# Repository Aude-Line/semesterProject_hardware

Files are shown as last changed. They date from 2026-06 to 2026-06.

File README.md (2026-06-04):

# CAD Gripper — Hardware Repository

## Intro

This repository contains all hardware files for the EHD actuated soft gripper project: CAD source files for laser-cut and 3D-printed parts, along with the electronics design for the control and power system.

---

## Repository Structure

```
cad_files/
├── laser_model_2D/        # 2D drawings (PDF) for laser-cut parts
├── source_laser/          # STEP files for laser-cut parts (2 mm acrylic)
└── source_3d_print/       # STEP files for 3D-printed parts (PLA)
```

---

## Electronics

The electronics are an improved version of the system used in the lab. The key change is that instead of the DC-DC converter being always enabled, its enable pin is now controlled by an ESP32-C6, chosen for its MicroROS compatibility. All components are soldered and mounted on the `elec_holder_main_plate` (laser-cut as part of the electronics box). The ESP is power via USB.

### Block Diagram

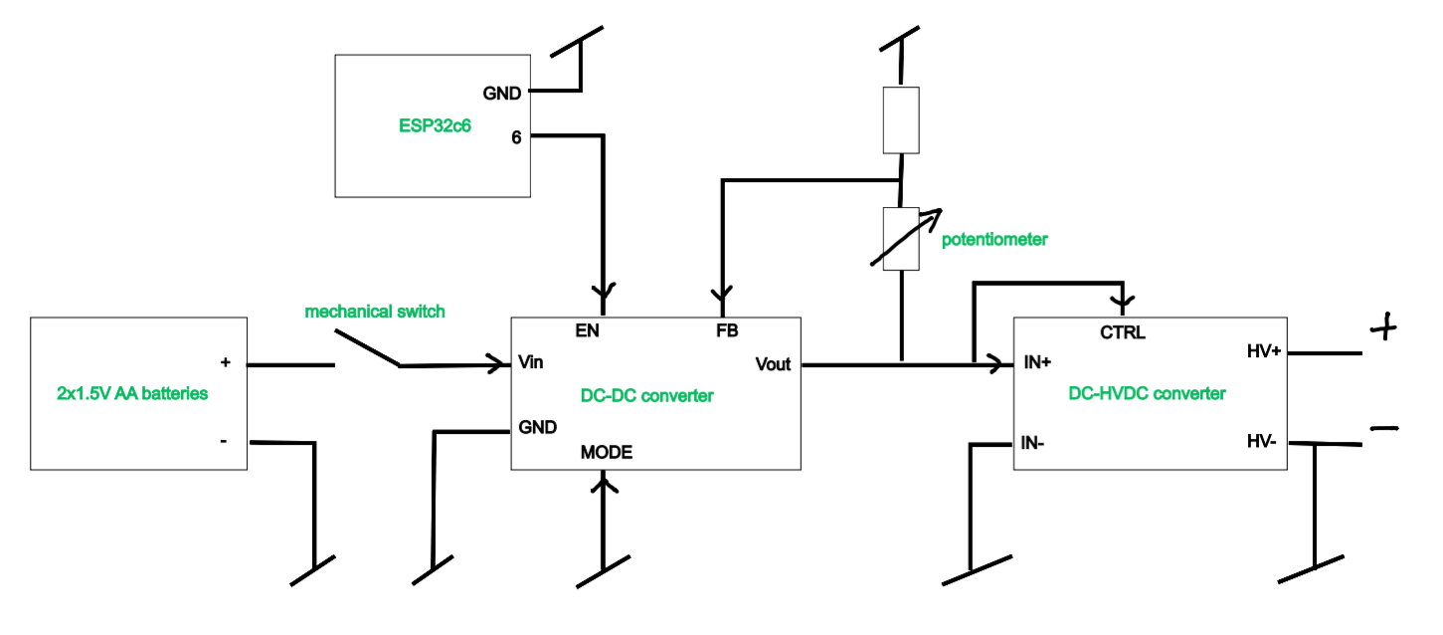
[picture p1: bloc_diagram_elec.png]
Block Diagram


### Components

| Qty | Component | Description |
|-----|---|---|
| 1 | ESP32-C6 dev board | Microcontroller — controls the DC-DC enable pin (https://docs.espressif.com/projects/esp-dev-kits/en/latest/esp32c6/esp32-c6-devkitm-1/user_guide.html)|
| 1 | DC-DC converter | Regulates the battery voltage to supply the HVDC-DC converter (https://www.ti.com/lit/ug/slvuco7/slvuco7.pdf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, https://www.ti.com/lit/ds/symlink/tpsm83100.pdf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)|
| 1 | HVDC-DC converter | High-voltage DC-DC — powers the EHD pump; output is linear to input (https://www.xppower.com/storage/portals/0/pdfs/SF_A_Series.pdf)|
| 1 | Potentiometer | Analog input for output voltage control |
| 1 | Mechanical switch | Safety switch — cuts the circuit |
| 2 | Proto board | Mounting support for the ESP32 and HVDC-DC converter |
| 2 | AA batteries | Main power source |
| 1 | Battery holder | |

---

## Assembly

### Parts List

**Laser-cut (2 mm acrylic):**
- `elec_holder_back_part1` / `elec_holder_back_part2` — Electronics enclosure back panels
- `elec_holder_front` — Electronics enclosure front panel
- `elec_holder_main_plate` — Main mounting plate
- `elec_holder_gripper_attachment` — Gripper-side attachment (top)
- `elec_holder_robot_attachment` — Robot arm-side attachment (bottom)
- `elec_holder_spacer_robot` — Spacer for robot attachment
- `gripper_attachment_silicone` — Silicone gripper attachment interface
- `gripper_direct_attachement_laser` — Direct gripper attachment (laser variant)

**3D-printed (PLA):**
- `elec_holder_bananaPlugs_holder` — Banana plug holder
- `elec_holder_wall_left` / `wall_right` — Side walls for electronics enclosure
- `elec_holder_devBoard_DCDC_holder` — DC-DC dev board mount
- `gripper_direct_attachement_3d` — Direct gripper attachment (3D variant)

---

### Electronics Box Assembly

> The box was originally designed to also house a pump and a liquid pouch. This was later abandoned to improve safety (separating electronics from liquid) and reduce the weight on the robot. Some holes on the top and bottom panels remain from that initial design. As a result, `elec_box part1` only needs to be laser-cut when the box is not used as a gripper support in direct contact with the robot and `elec_box part2` file contains the attachemnt for the robot ant the gripper.

**Components:**
- 1× `elec_holder_wall_right` (3D-printed)
- 1× `elec_holder_wall_left` (3D-printed)
- 1× `elec_holder_devBoard_DCDC_holder` (3D-printed)
- 1× `elec_holder_bananaPlugs_holder` (3D-printed)
- 1× `elec_holder_back_part1` (laser-cut)
- All electronic components
- 12× heat inserts (https://www.bossard.com/ch-en/eshop/threaded-inserts-for-press-in-for-plastic-materials/tappex-multisert-003-004/p/37896/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)

**Assembly steps:**
1. Install the heat inserts
2. Attach the electronics to their respective layers
3. Attach the bottom and both back panels to the walls
4. Slide the layers in, routing the switch and potentiometer to the back panel
5. Close the box with the front panel and screws

> Refer to the assembly video below — note that not all components are rendered.

https://github.com/user-attachments/assets/7390a7a7-a0ae-449d-9c6a-b7f72b6546bb

---

### Gripper Assembly

**Components:**
- 1× `gripper_direct_attachement_3d` (3D-printed)
- 2× silicone modules
- 1× `gripper_attachment_silicone` (laser-cut, 2 mm acrylic)
- 2× heat inserts (https://www.bossard.com/ch-en/eshop/threaded-inserts-for-press-in-for-plastic-materials/tappex-multisert-003-004/p/37896/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)
- Tubing

**Assembly steps:**
1. Connect tubes to the silicone gripper modules
2. Glue the modules onto the small attachment pieces
3. Screw the small attachments into the attachment plate — the modular design allows spacing adjustment and module swapping
4. Install heat inserts in the 3D-printed part
5. Screw the 3D-printed part onto the robot
6. Slide the attachment plate into the 3D-printed part and screw in place if needed

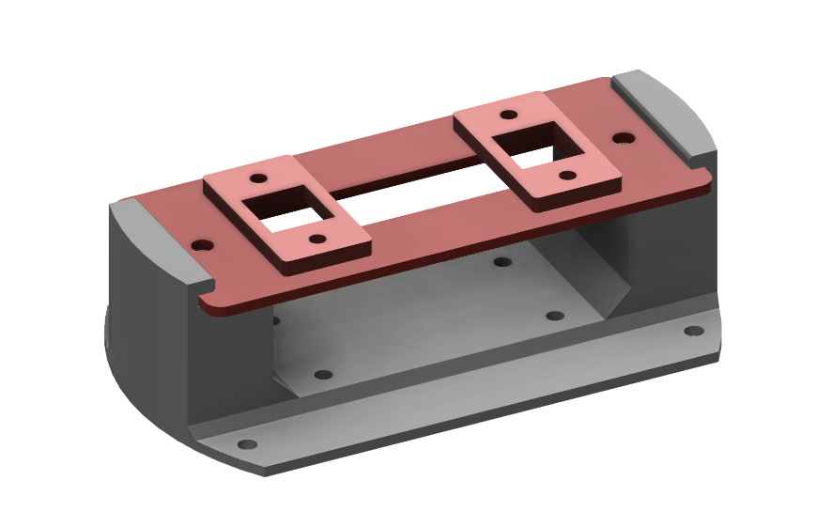
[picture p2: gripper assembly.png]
Gripper Assembly


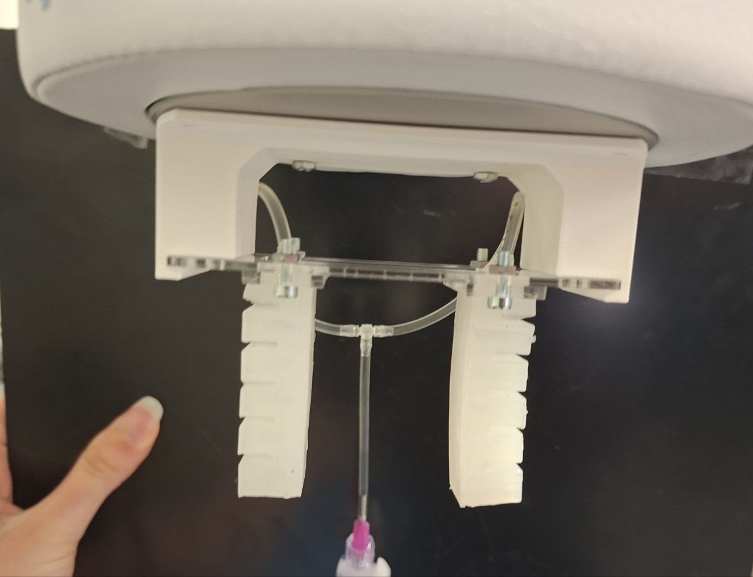
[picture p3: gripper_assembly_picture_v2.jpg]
Gripper Assembly Photo


### Full Assembly

Once every part is tested and validated, the pump can be connected:

1. Mount a liquid reservoir at an elevated position
2. Attach the pump between the reservoir and the gripper tube
3. Fill the system with liquid
4. Connect the pump to the banana plug connectors

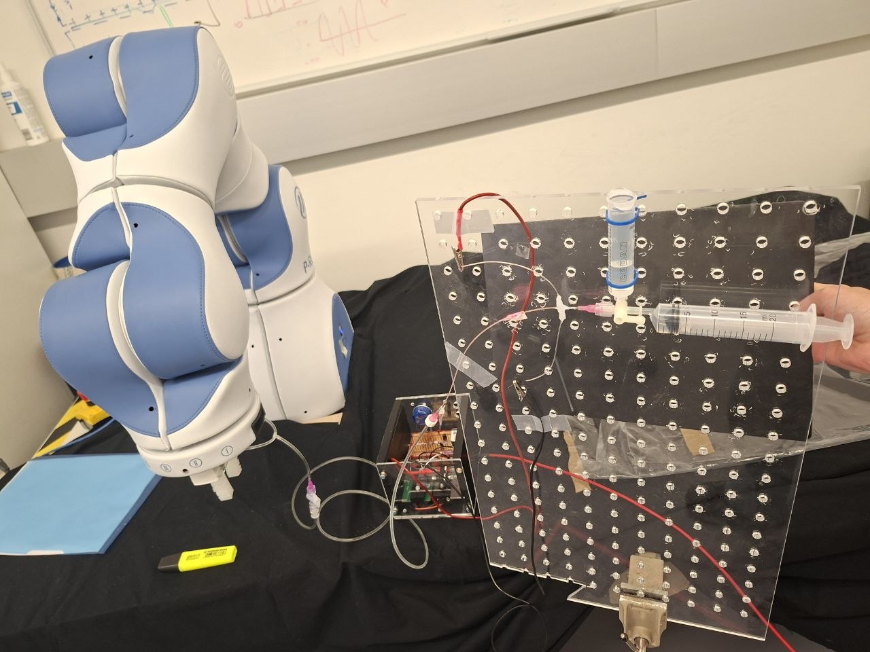
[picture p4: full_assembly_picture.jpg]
Full Assembly


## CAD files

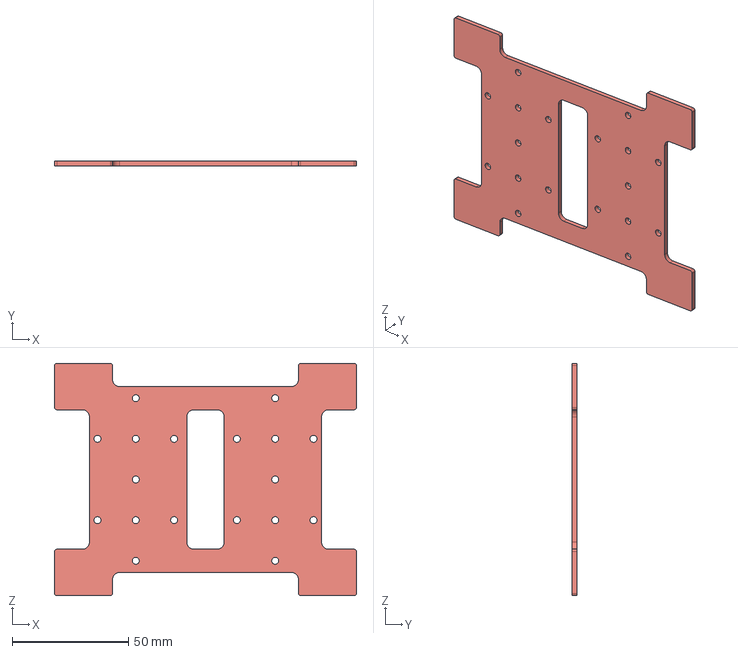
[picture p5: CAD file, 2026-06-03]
cad_files/source_laser/elec_holder_main_plate.step
130.0 x 2.00 x 100.0 mm

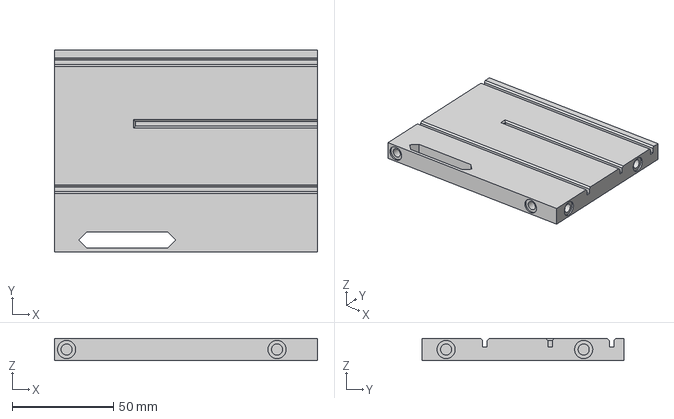
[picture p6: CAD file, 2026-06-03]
cad_files/source_3d_print/elec_holder_wall_left.step
130.0 x 100.0 x 11.0 mm

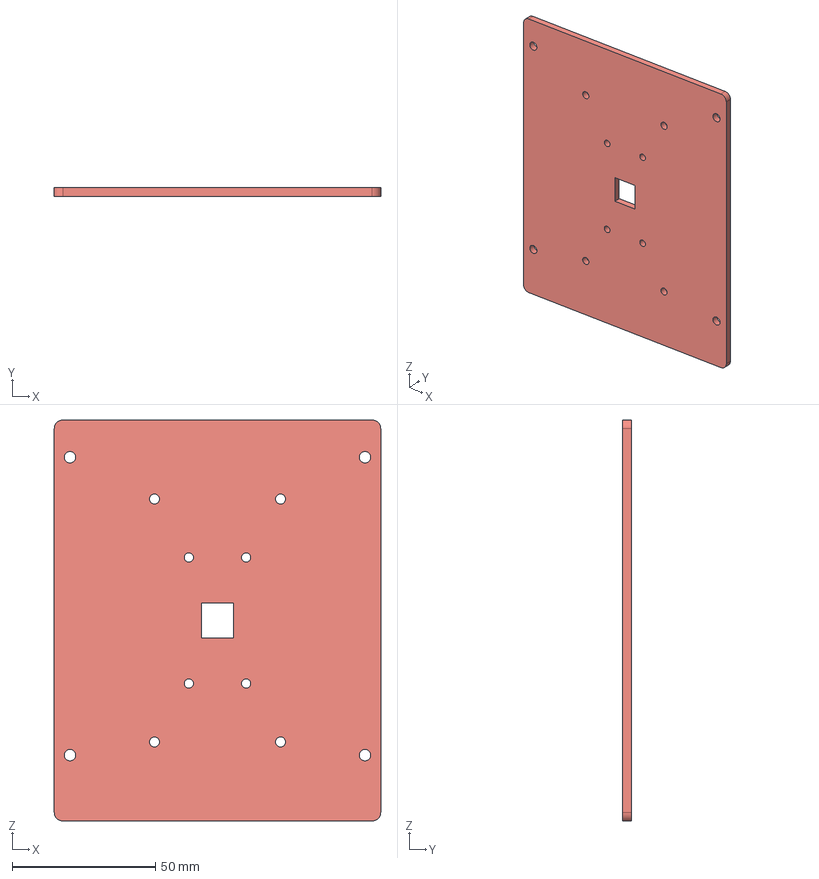
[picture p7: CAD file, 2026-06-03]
cad_files/source_laser/elec_holder_robot_attachment.step
114.0 x 3.00 x 140.0 mm

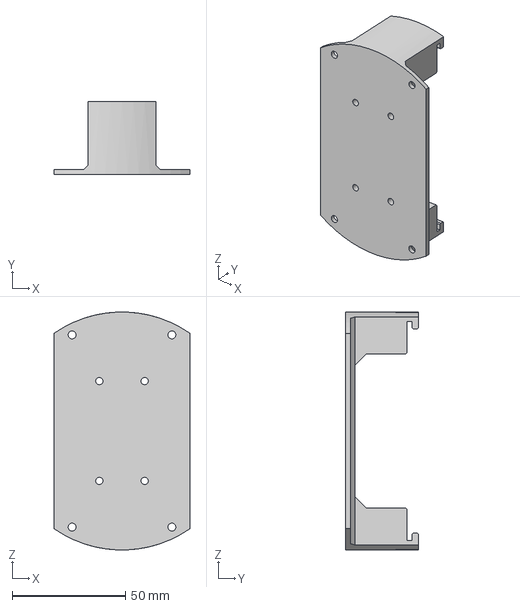
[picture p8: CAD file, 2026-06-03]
cad_files/source_3d_print/gripper_direct_attachement_3d.step
60.0 x 32.0 x 105.0 mm

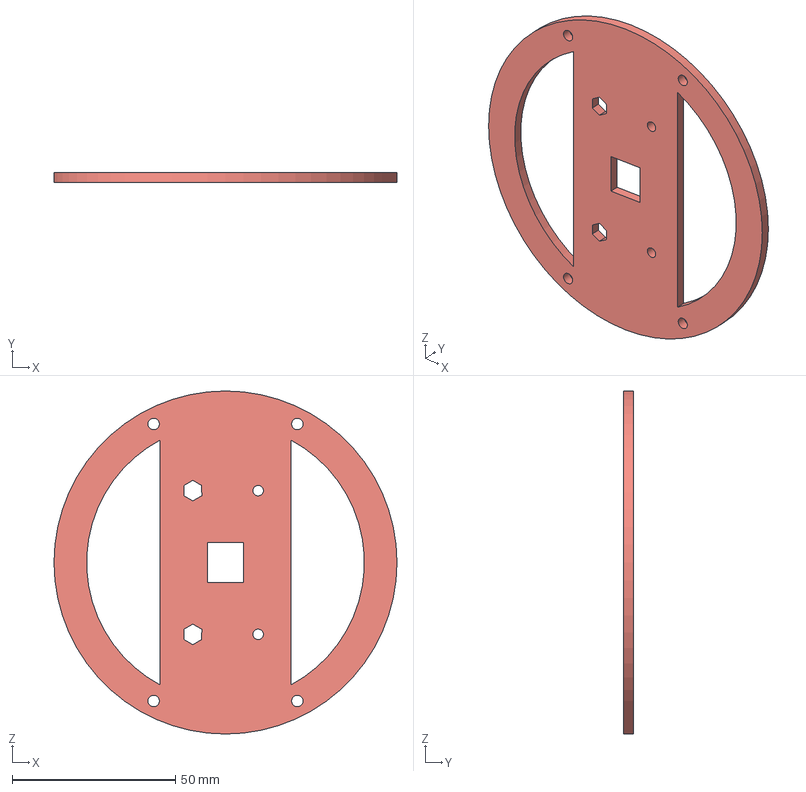
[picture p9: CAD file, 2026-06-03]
cad_files/source_laser/elec_holder_spacer_robot.step
105.0 x 3.00 x 105.0 mm

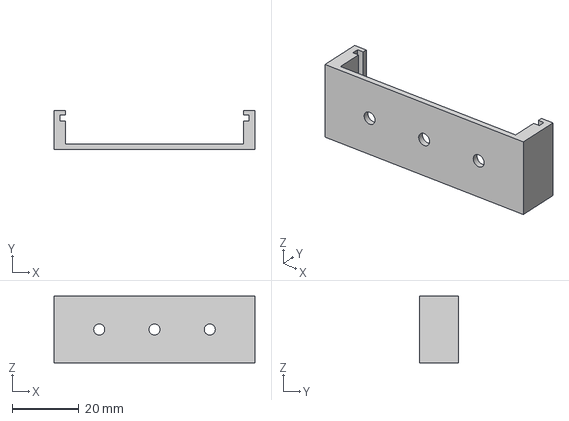
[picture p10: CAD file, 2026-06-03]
cad_files/source_3d_print/elec_holder_devBoard_DCDC_holder.step
60.0 x 11.5 x 20.0 mm

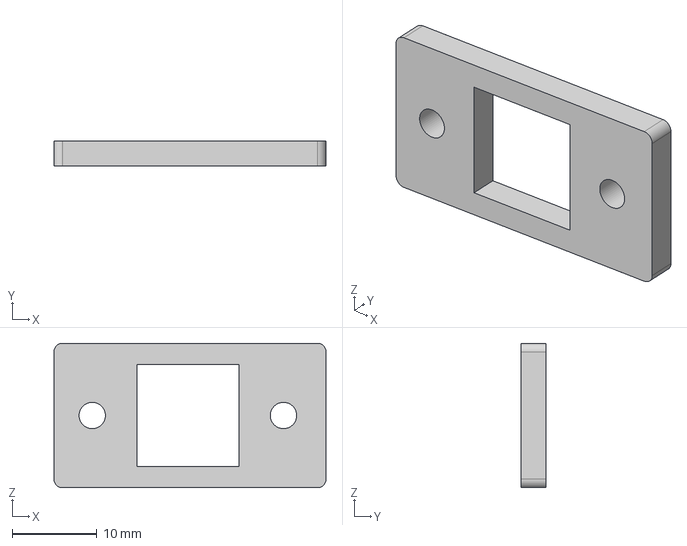
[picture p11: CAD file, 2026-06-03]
cad_files/source_laser/gripper_attachment_silicone.step
32.0 x 3.00 x 17.0 mm

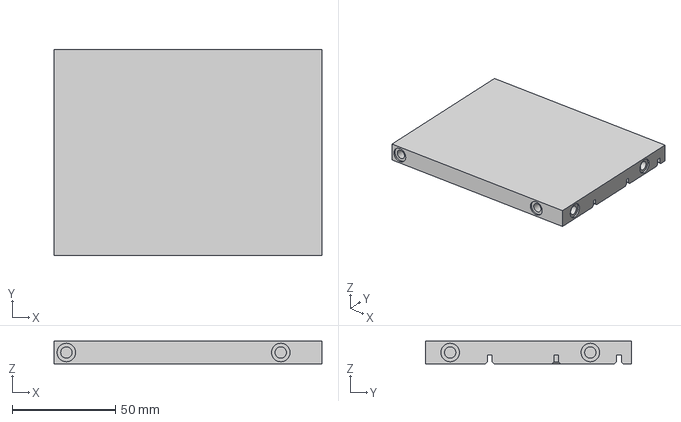
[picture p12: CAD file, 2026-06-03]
cad_files/source_3d_print/elec_holder_wall_right.step
130.0 x 100.0 x 11.0 mm

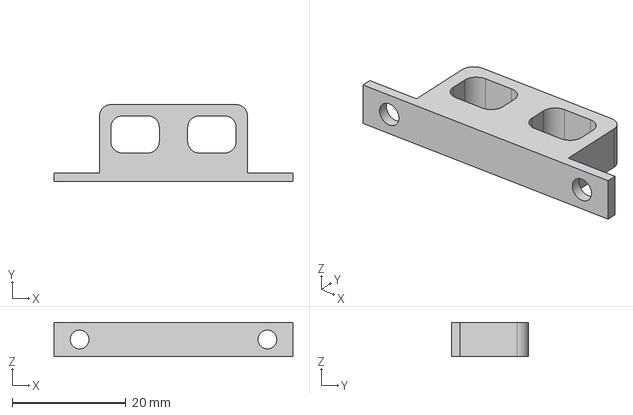
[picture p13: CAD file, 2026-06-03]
cad_files/source_3d_print/elec_holder_bananaPlugs_holder.step
42.0 x 13.5 x 6.00 mm

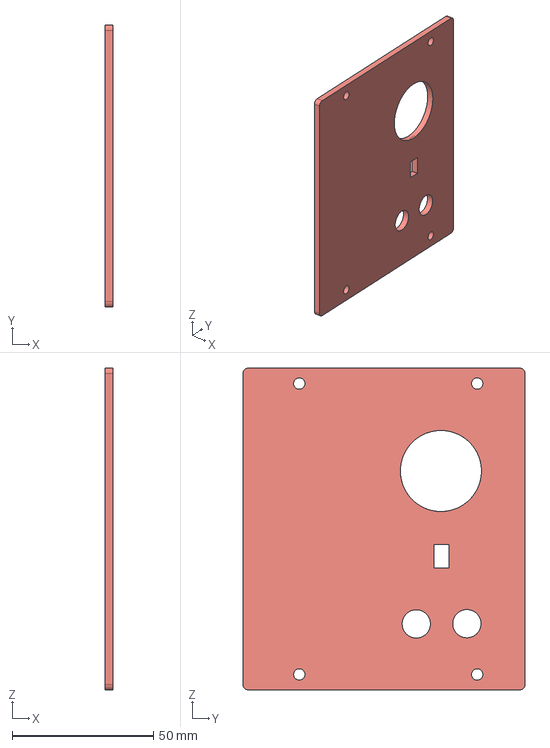
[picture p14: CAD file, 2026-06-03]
cad_files/source_laser/elec_holder_back_part1.step
3.00 x 100.0 x 114.0 mm

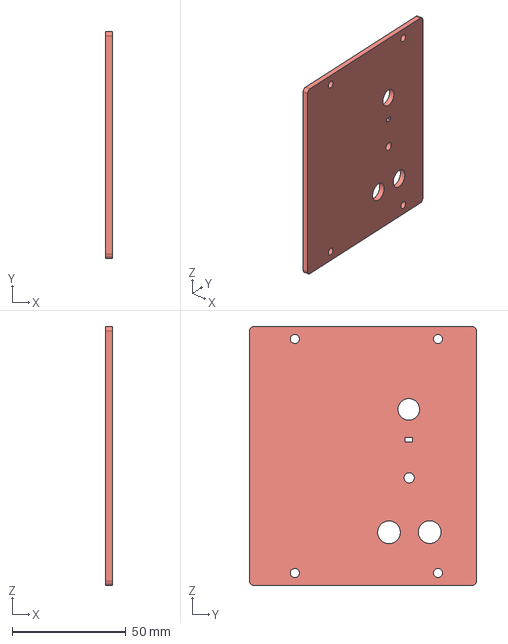
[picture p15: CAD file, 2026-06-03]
cad_files/source_laser/elec_holder_back_part2.step
3.00 x 100.0 x 114.0 mm

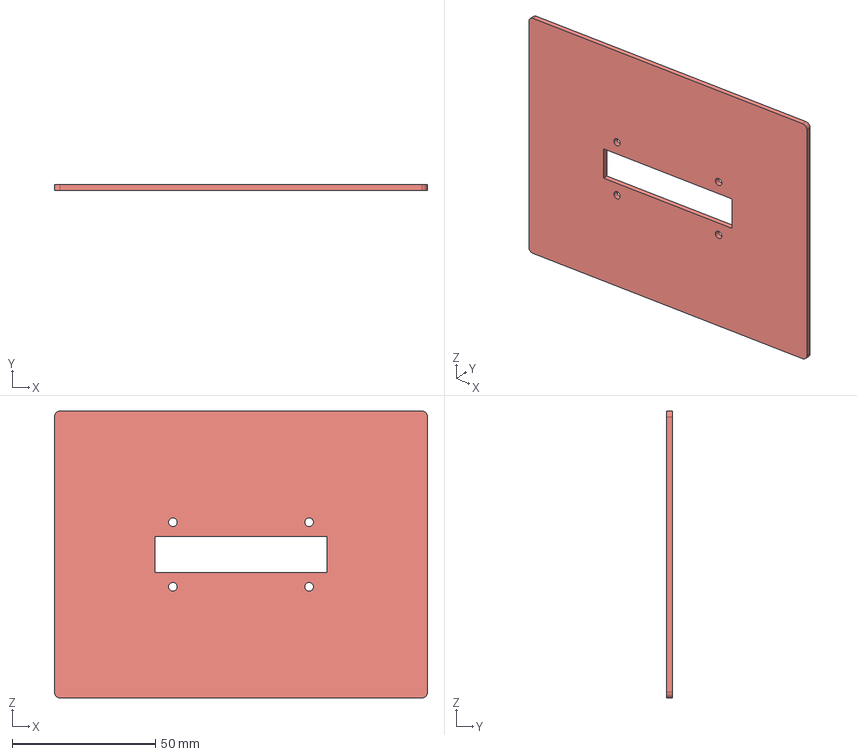
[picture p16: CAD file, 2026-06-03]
cad_files/source_laser/elec_holder_gripper_attachment.step
130.0 x 2.00 x 100.0 mm

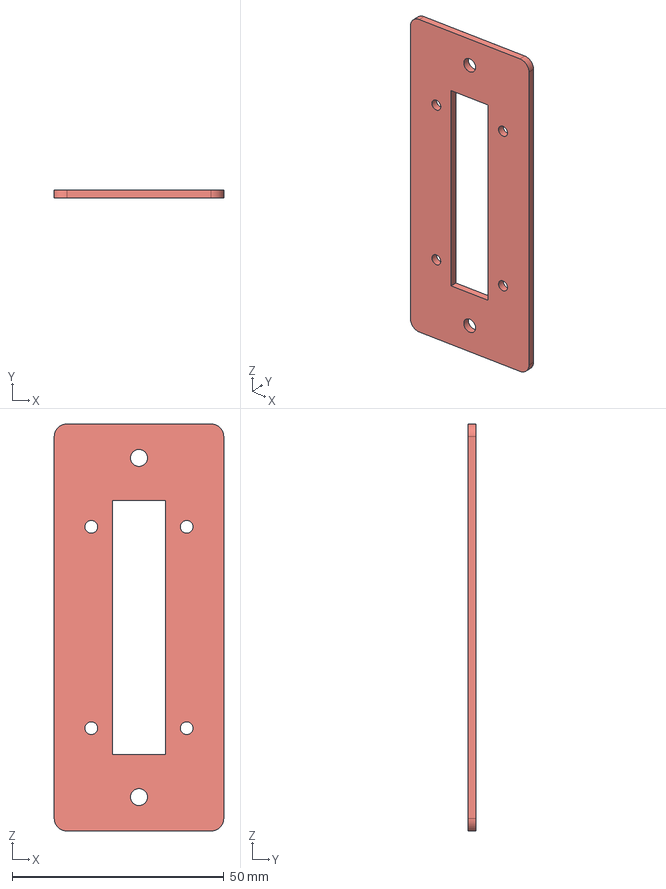
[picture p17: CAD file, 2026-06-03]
cad_files/source_laser/gripper_direct_attachement_laser.step
40.0 x 2.00 x 96.0 mm

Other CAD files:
cad_files/source_laser/elec_holder_front.step

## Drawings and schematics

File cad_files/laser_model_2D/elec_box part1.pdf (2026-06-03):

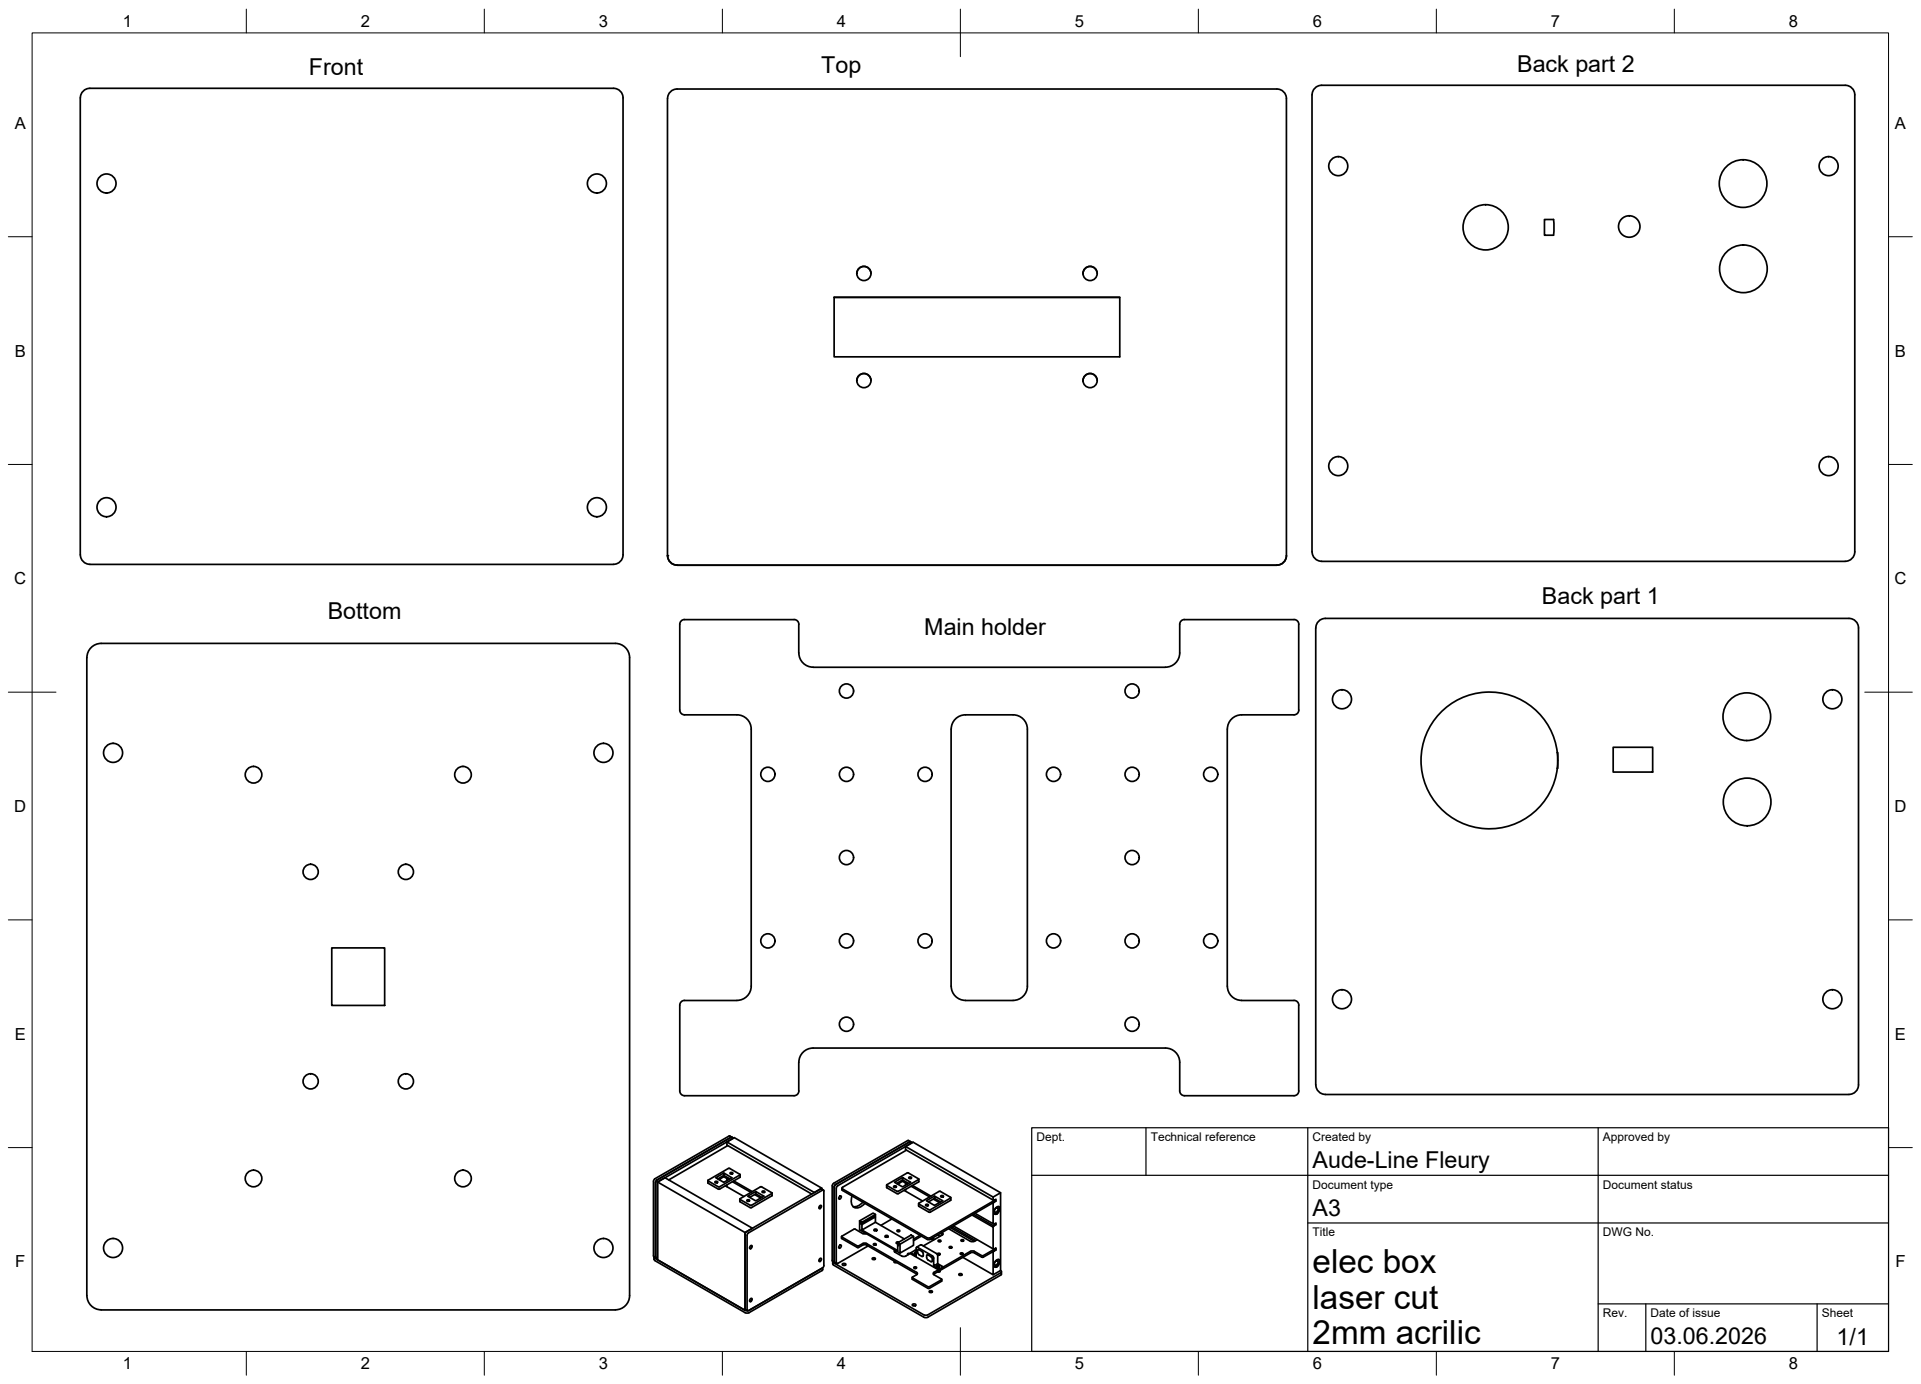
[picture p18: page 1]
Title; DWG No.; Rev.; Date of issue; Sheet; 2mm acrilic; laser cut; elec box; Back part 1; Back part 2; Main holder

Dept. | Technical reference | Created by Aude-Line Fleury | Approved by

Document type A3 | Document status

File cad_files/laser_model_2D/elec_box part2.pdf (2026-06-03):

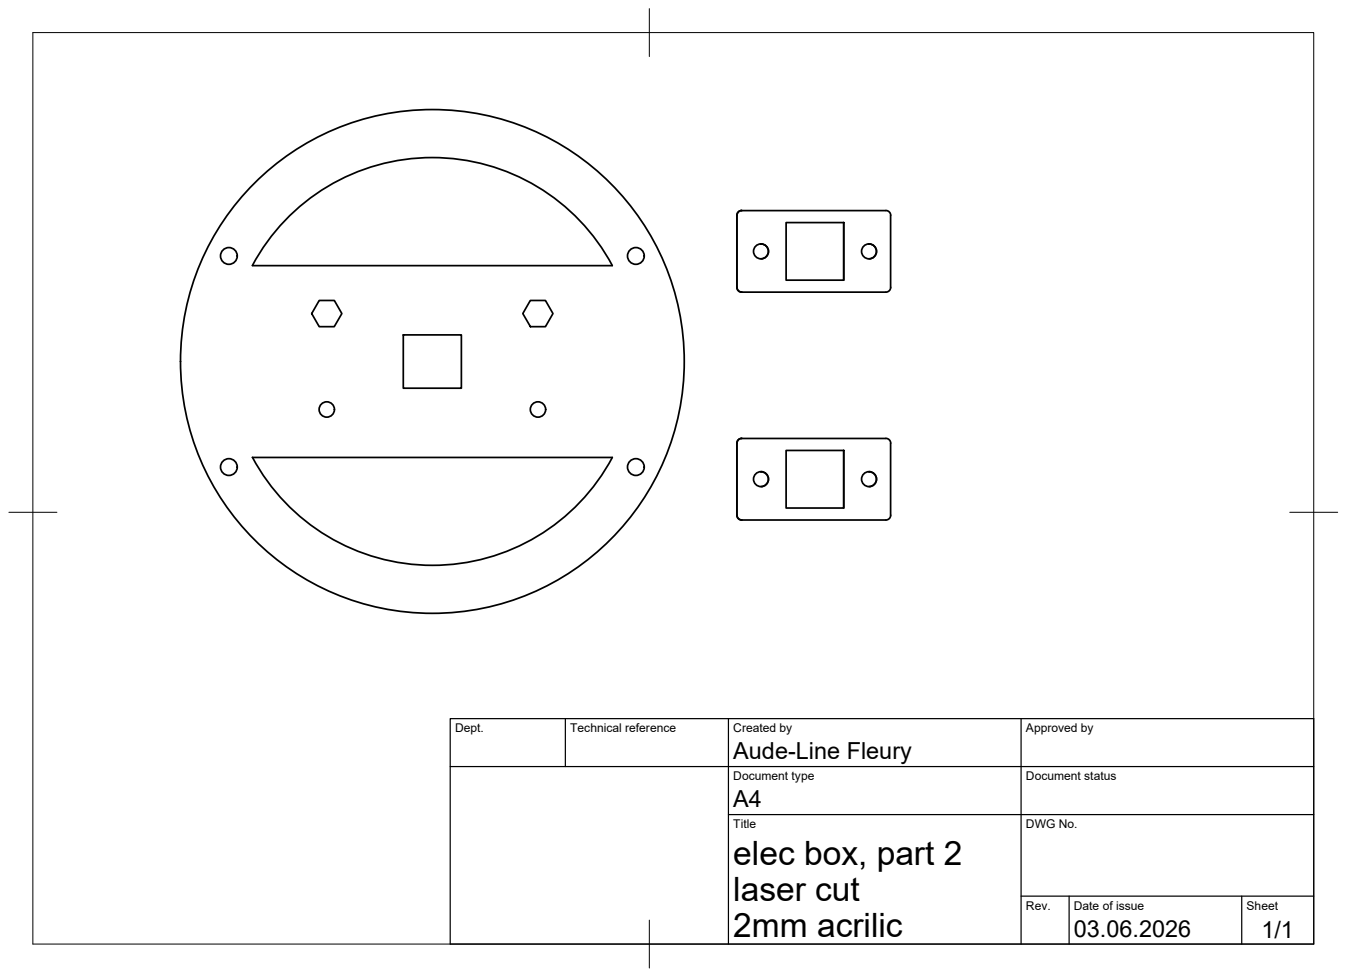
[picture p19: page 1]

Dept. | Technical reference | Created by Aude-Line Fleury | Approved by

Document type A4 | Document status

Title elec box, part 2 laser cut 2mm acrilic | DWG No.

Rev. | Date of issue 03.06.2026 | Sheet 1/1

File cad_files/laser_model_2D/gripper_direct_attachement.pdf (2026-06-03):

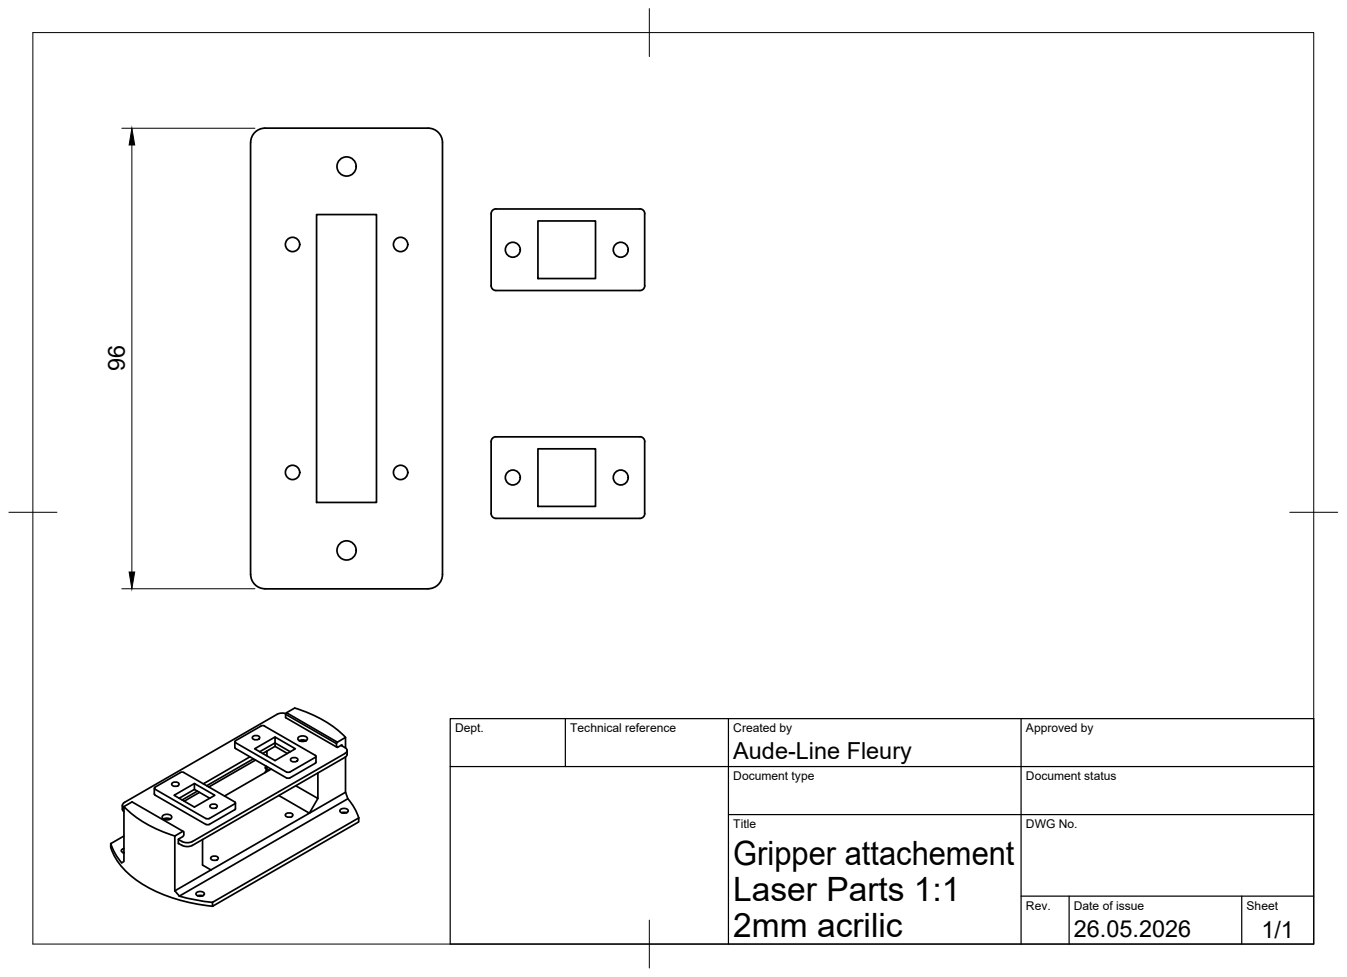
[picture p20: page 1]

Aude-Line Fleury 96

Dept. | Technical reference | Created by | Approved by

Document type | Document status

Title Gripper attachement Laser Parts 1:1 2mm acrilic | DWG No.

Rev. | Date of issue 26.05.2026 | Sheet 1/1

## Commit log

2026-06-03 modify the folder structure
    [elec_holder_back_part1.step, elec_holder_back_part2.step, elec_holder_bananaPlugs_holder.step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]
2026-06-04 continue readme
    [elec_holder_devBoard_DCDC_holder.step]
